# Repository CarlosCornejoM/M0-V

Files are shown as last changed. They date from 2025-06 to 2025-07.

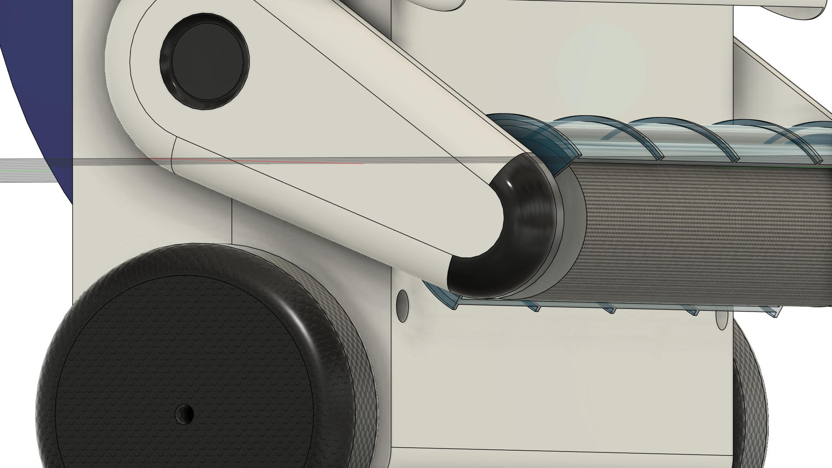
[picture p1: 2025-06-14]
Design/C.png

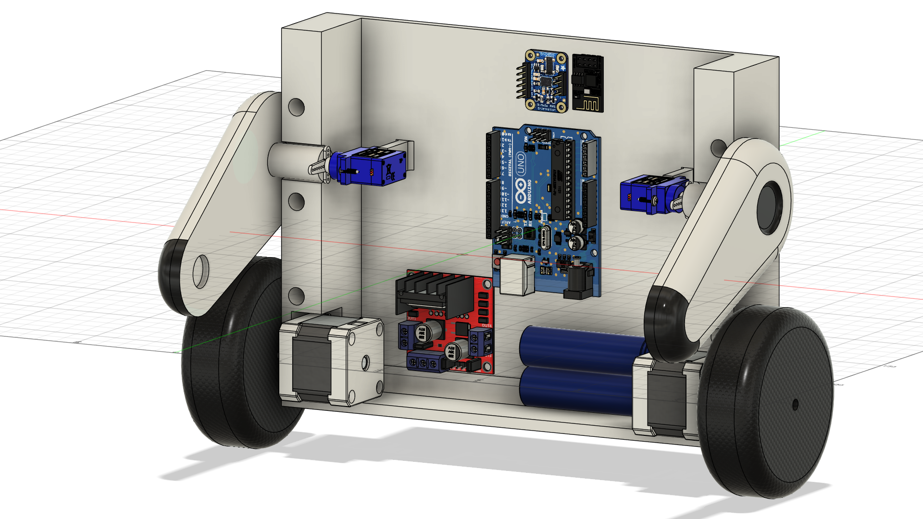
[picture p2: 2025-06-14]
Design/B.png

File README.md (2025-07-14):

# Robot tipo WALL·E con ESP8266 y Arduino

Este repositorio contiene el código fuente y documentación de un robot inspirado en WALL·E (modelo M0-V) que emplea un Arduino (Uno/Nano) para control y un ESP8266 como interfaz web para monitoreo y control remoto en tiempo real.

## Descripción general

### Arduino Uno/Nano:
- Inicializa y calibra el sensor MPU6050 con filtros digitales y pasa-bajos de 20Hz
- Controla dos motores paso a paso NEMA17 (200 pasos/rev) con drivers DRV8825
- Mueve dos servomotores SG90 (0-180°) con control suavizado
- Ejecuta un control PID para equilibrar el sistema pendular invertido con anti-windup
- Gestiona motor DC con control PWM y H-bridge
- Envía telemetría periódica por puerto serie (115200 bps)

### ESP8266:
- Se conecta a la red WiFi (configurable en ESP8266.ino)
- Sirve una interfaz web desde index_html.h
- Establece un WebSocket en el puerto 81 para comunicación bidireccional
- Emite un JSON con el estado completo cada 20 ms
- Recibe comandos desde la página web para control remoto

### Interfaz web:
- Panel de valores de sensor (pitch, roll, yaw, aceleración, temperatura)
- Consola serial con logs en tiempo real
- Gráficos de latencia WebSocket, RPM de steppers y parámetros PID
- Controles para ajustar servos, RPM, PID y reproducir audio
- Monitoreo de estado de LEDs (ESP, Arduino, DC)
- Soporte para gamepad/joystick

## Especificaciones técnicas

### Hardware requerido:
- Arduino Uno + ESP8266
- MPU6050 (giroscopio/acelerómetro)
- 2x Motor NEMA17 con drivers DRV8825
- 2x Servomotor SG90
- Motor DC con H-bridge
- Componentes electrónicos varios

### Características del sistema:
- Comunicación serie: 115200 bps
- Velocidad I2C: 100kHz (estabilidad mejorada)
- Filtro digital MPU6050: 20Hz pasa-bajos
- Control PID: 20ms de período
- Telemetría MPU: 20ms de período
- WebSocket: 20ms de actualización
- MAX_RPM configurable: 30 RPM por defecto

## Flujo de funcionamiento

### 1. Inicialización:
- Arduino arranca módulos: parámetros, steppers, motores DC, MPU, comunicación serie, PID
- ESP8266 arranca en modo station, se conecta al SSID configurado y lanza el servidor HTTP y WebSocket

### 2. Telemetría:
Arduino envía mensajes serial con prefijos:
- `[ANGLES,pitch,roll,yaw,temp]` - Ángulos y temperatura
- `[RPM1,val]`, `[RPM2,val]` - RPM de steppers
- `[PID,error,output,integral]` - Estados del PID
- ESP8266 parsea y actualiza su estado interno
- Cada 20 ms envía por WebSocket un JSON con todos los campos

### 3. Interfaz web:
- Conexión WebSocket en `ws://<IP>:81/`
- Actualización en tiempo real de valores y gráficos
- Envío de comandos JSON:
  - `{"cmd":"setServos","a1":...,"a2":...}` - Control de servos
  - `{"cmd":"setMRPM","rpm":...}` - RPM máximo de steppers
  - `{"cmd":"setPID","sp":...,"kp":...,"ki":...,"kd":...}` - Parámetros PID
  - `{"cmd":"playMelody"}`, `{"cmd":"playAudio"}` - Reproducción audio
  - `{"cmd":"startSiren"}`, `{"cmd":"stopSiren"}` - Control sirena
  - `{"cmd":"espOn"}/{"cmd":"espOff"}` - LEDs ESP
  - `{"cmd":"unoOn"}/{"cmd":"unoOff"}` - LEDs Arduino
  - `{"cmd":"dcOn"}/{"cmd":"dcOff"}` - Motor DC
  - `{"cmd":"JOY_L","x":...,"y":...}` - Control diferencial steppers
  - `{"cmd":"gamepad",...}` - Control por gamepad

### 4. Control por gamepad:
- La página captura un joystick Gamepad API
- Stick izquierdo: comando JOY_L (control diferencial steppers)
- Stick derecho: ajuste automático de servos
- Gatillos: nivel DC
- Botones mapeados a acciones definidas por el usuario

## Configuración de pines

### Arduino:
- **MPU6050**: I2C (SDA/SCL)
- **Steppers**: DIR1=2, STEP1=3, DIR2=4, STEP2=5, EN1=A0, EN2=A1
- **H-bridge**: ENA=14, ENB=7, IN1=8, IN2=12, IN3=10, IN4=13
- **Servos**: SERVO1=6, SERVO2=9
- **Motor DC**: PWM=11
- **Ultrasonido**: TRIG=A3, ECHO=6
- **LED**: LED_BUILTIN

### ESP8266:
- **Comunicación serie**: RX/TX con Arduino
- **LED**: D4 (GPIO2)
- **WiFi**: Antena integrada

## Algoritmos implementados

### Control PID:
- Período: 20ms
- Anti-windup: Integral limitada a ±1000
- Filtro derivativo: Pasa-bajos con coeficiente 0.7
- Salida limitada a MAX_RPM

### Control de steppers:
- Suavizado exponencial: Factor 0.15
- Aceleración: 2x velocidad máxima
- Frecuencia de ejecución: 500Hz máximo
- Habilitación automática por velocidad

### Filtrado MPU6050:
- Filtro digital interno: 20Hz
- Filtro pasa-bajos software: Coeficiente 0.8
- Verificación de conexión continua
- Manejo de errores robusto

## Configuración

### 1. En ESP8266.ino, ajusta:
```cpp
const char* ssid     = "MOV";
const char* password = "12345678";
```

### 2. Verifica los pines en Param.ino y ESP8266.ino

### 3. Flashea primero el firmware de Arduino, luego el del ESP8266

### 4. Abre el navegador en la IP mostrada por el ESP en el monitor serie

## Optimizaciones implementadas

### Rendimiento:
- Filtros de software para reducir ruido
- Suavizado exponencial en steppers
- Telemetría adaptativa (solo envía si hay cambios significativos)
- Frecuencias de ejecución optimizadas

### Estabilidad:
- Velocidad I2C reducida (100kHz)
- Filtros anti-jitter en steppers
- Verificación de conexión MPU6050
- Manejo de errores en comunicación serie

### Eficiencia:
- Reducción de spam en telemetría
- Buffers optimizados
- Timers independientes para cada módulo
- Control de flujo en WebSocket

## Roadmap

- Optimización de filtros del MPU6050 y suavizado de steppers
- Mejoras en logging y manejo de errores en la web
- Implementación de PCB personalizada
- Soporte para múltiples sensores
- Integración con ROS (Robot Operating System)
- Modo autónomo con navegación

## Troubleshooting

### Problemas comunes:
- **MPU6050 se corrompe**: Verificar conexiones I2C y alimentación estable
- **Steppers con jitter**: Ajustar SMOOTH_FACTOR y verificar drivers
- **WebSocket desconecta**: Verificar potencia de señal WiFi
- **PID inestable**: Ajustar parámetros Kp, Ki, Kd gradualmente

### Logs de debug:
- Monitor serie Arduino: Estados de sensores y actuadores
- Consola web: Comunicación WebSocket y errores JavaScript
- Debug ESP8266: Información de conexión WiFi y memoria

¡Gracias por tu interés! Cualquier issue o PR es bienvenido.

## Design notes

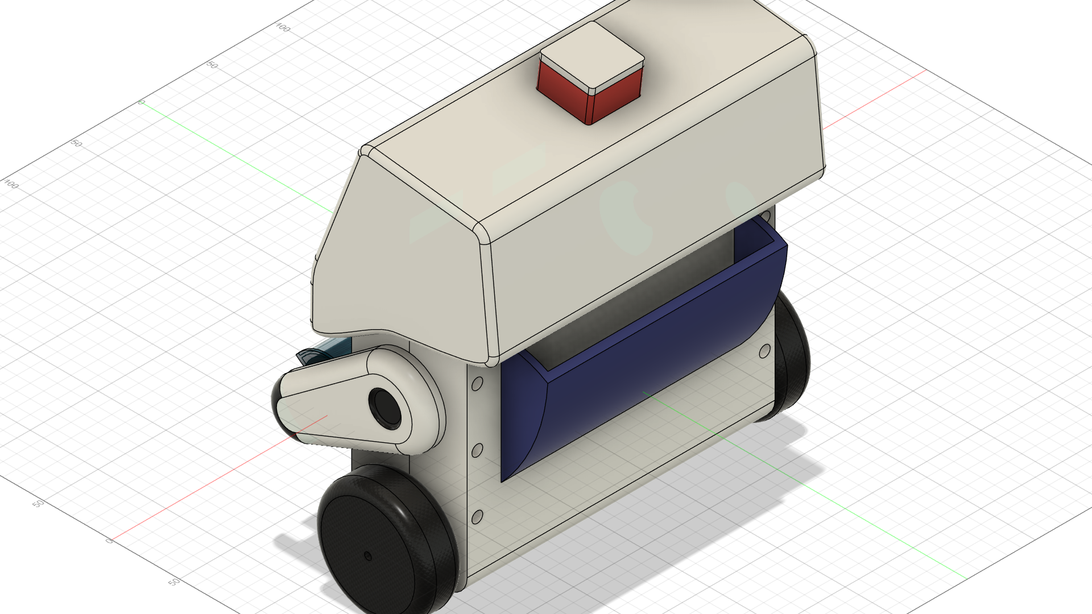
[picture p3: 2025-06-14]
Design/E.png

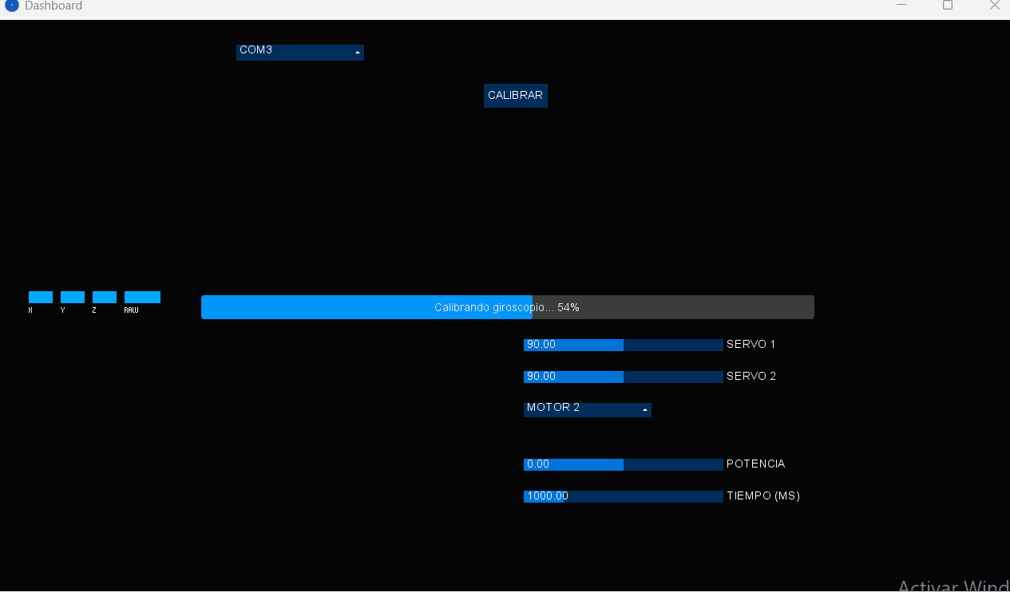
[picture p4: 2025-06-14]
Design/Animation3.gif

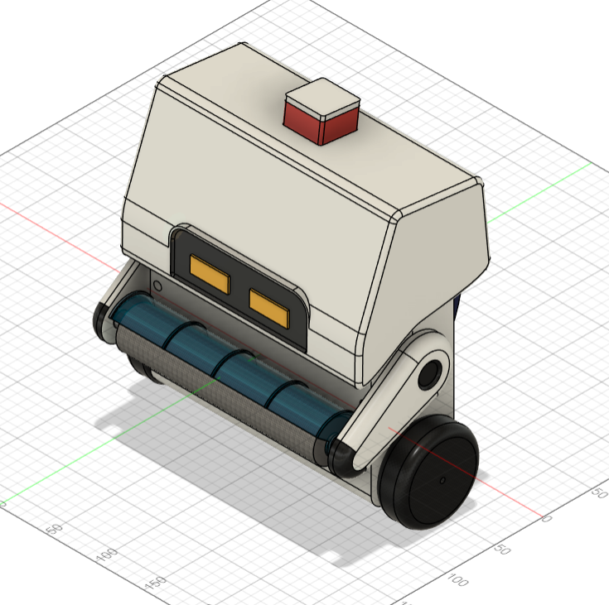
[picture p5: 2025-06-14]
Design/A.png

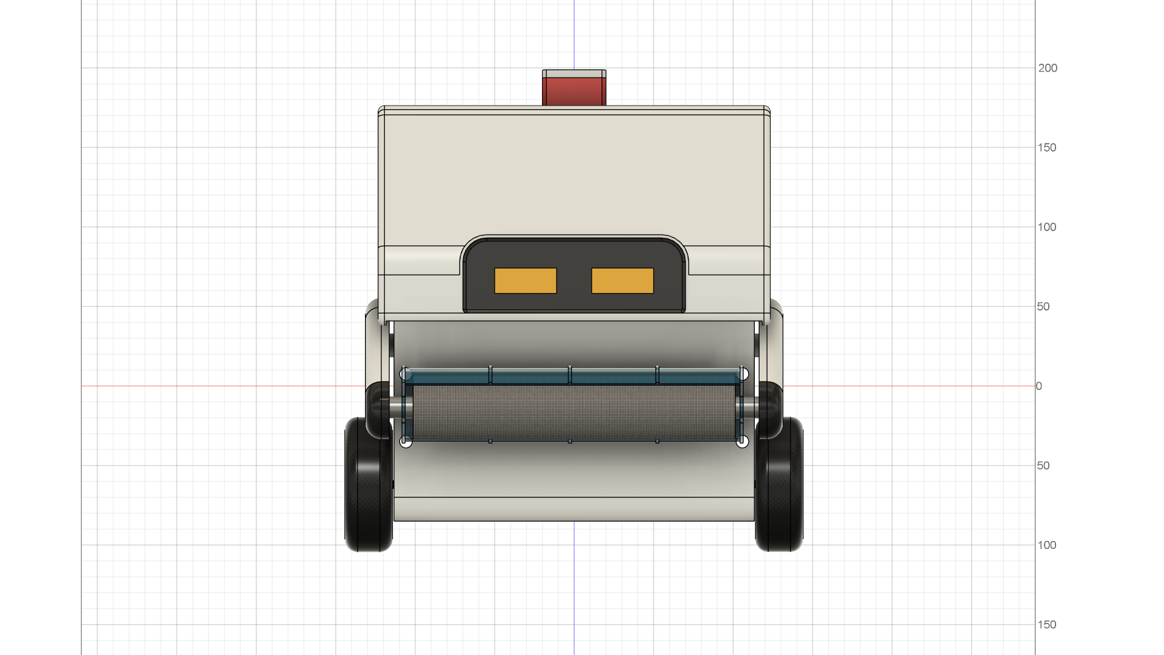
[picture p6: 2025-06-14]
Design/D.png

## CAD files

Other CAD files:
Design/experimento.f3z

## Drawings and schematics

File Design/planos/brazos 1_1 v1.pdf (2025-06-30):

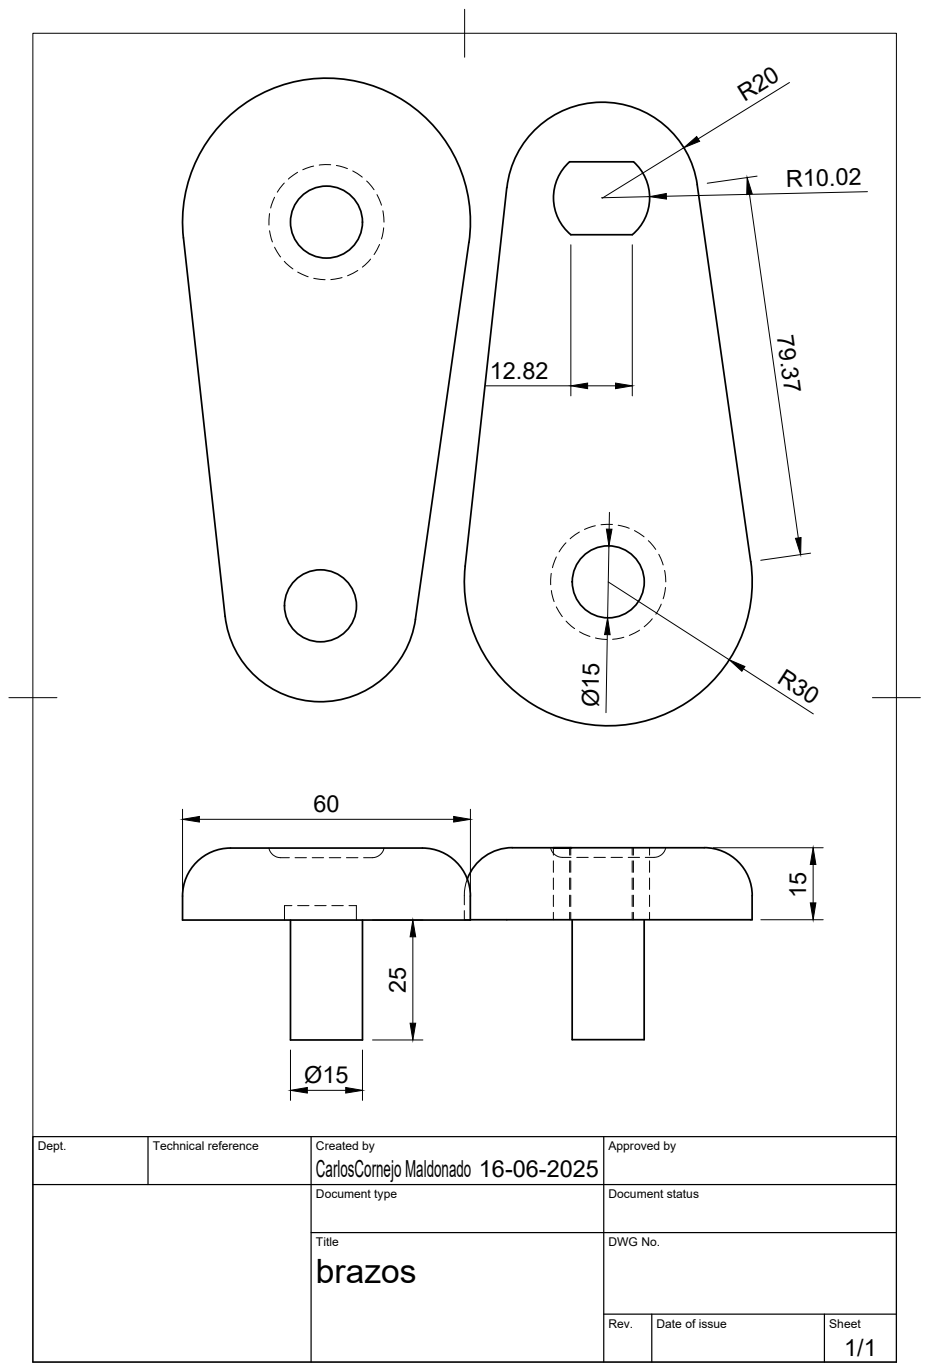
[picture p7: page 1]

Dept. | Technical reference | Created by CarlosCornejo Maldonado 16-06-2025 | Approved by

Document type | Document status

Title brazos | DWG No.

Rev. | Date of issue | Sheet 1/1

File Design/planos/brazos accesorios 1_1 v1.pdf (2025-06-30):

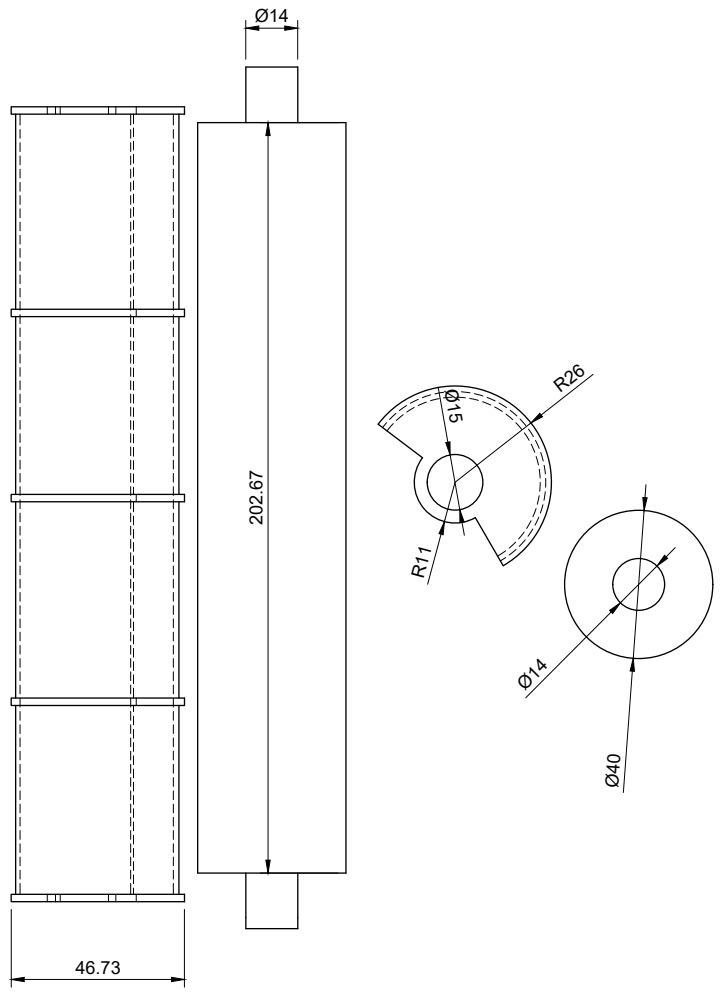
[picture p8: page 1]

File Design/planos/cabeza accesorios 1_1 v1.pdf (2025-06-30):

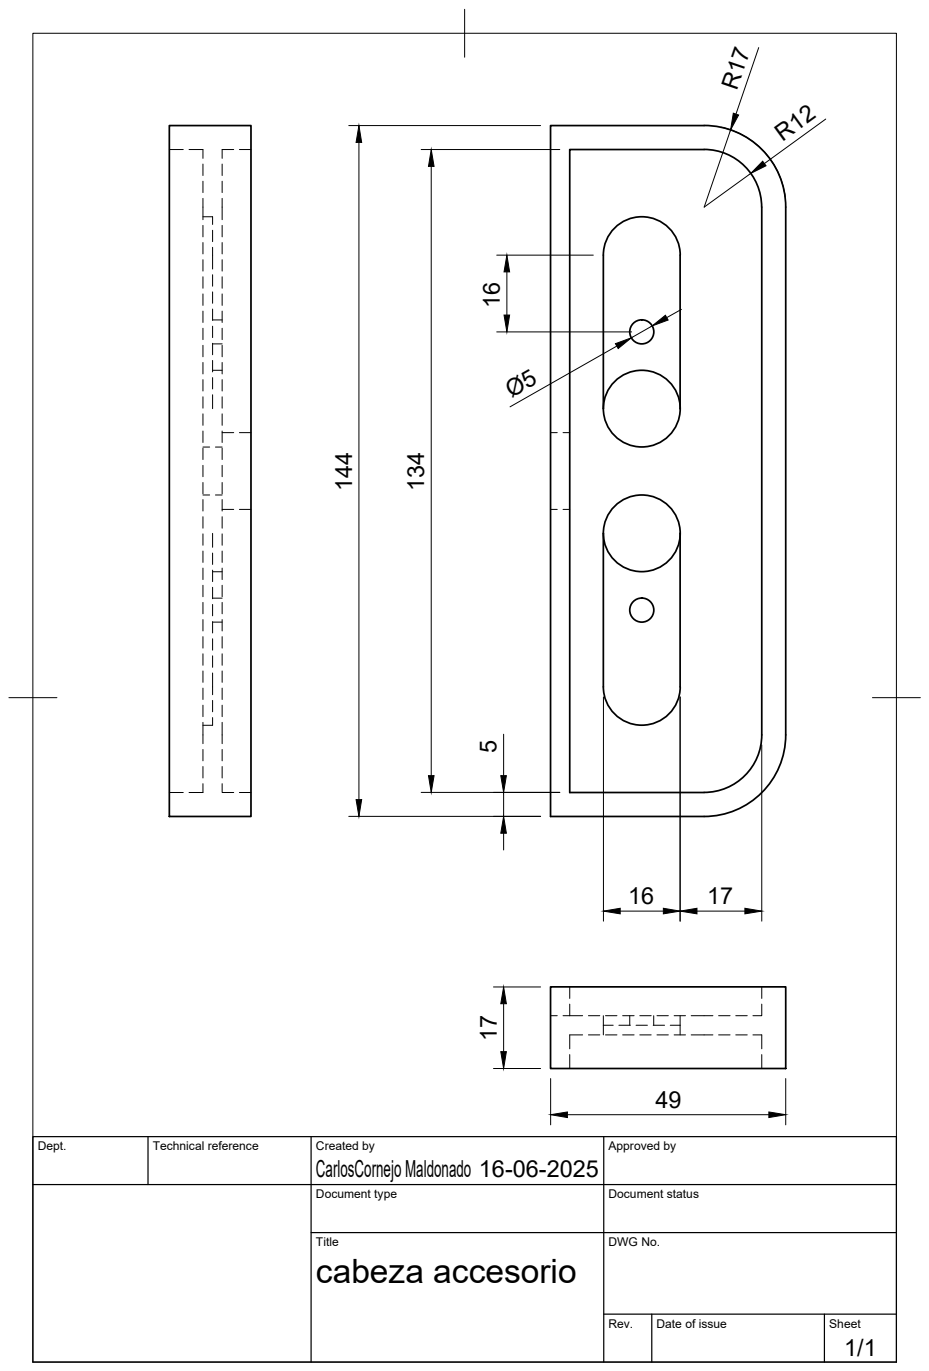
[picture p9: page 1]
CarlosCornejo Maldonado 144

Dept. | Technical reference | Created by 16-06-2025 | Approved by

Document type | Document status

Title cabeza accesorio | DWG No.

Rev. | Date of issue | Sheet 1/1

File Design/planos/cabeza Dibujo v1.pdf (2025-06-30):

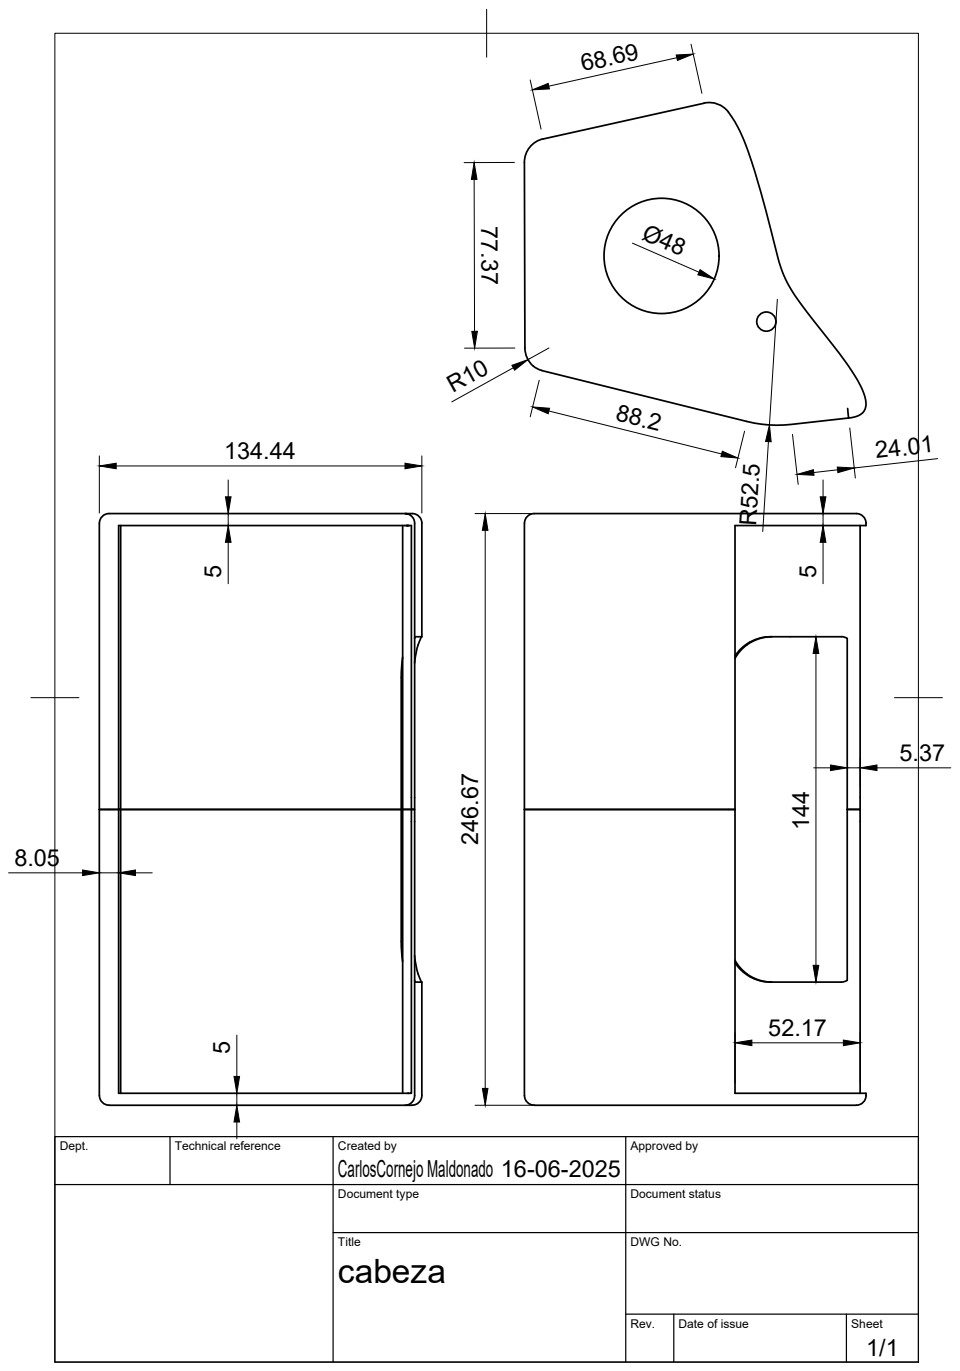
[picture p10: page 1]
CarlosCornejo Maldonado77.37

Dept. | Technical reference | Created by 16-06-2025 | Approved by

Document type | Document status

Title cabeza | DWG No.

Rev. | Date of issue | Sheet 1/1

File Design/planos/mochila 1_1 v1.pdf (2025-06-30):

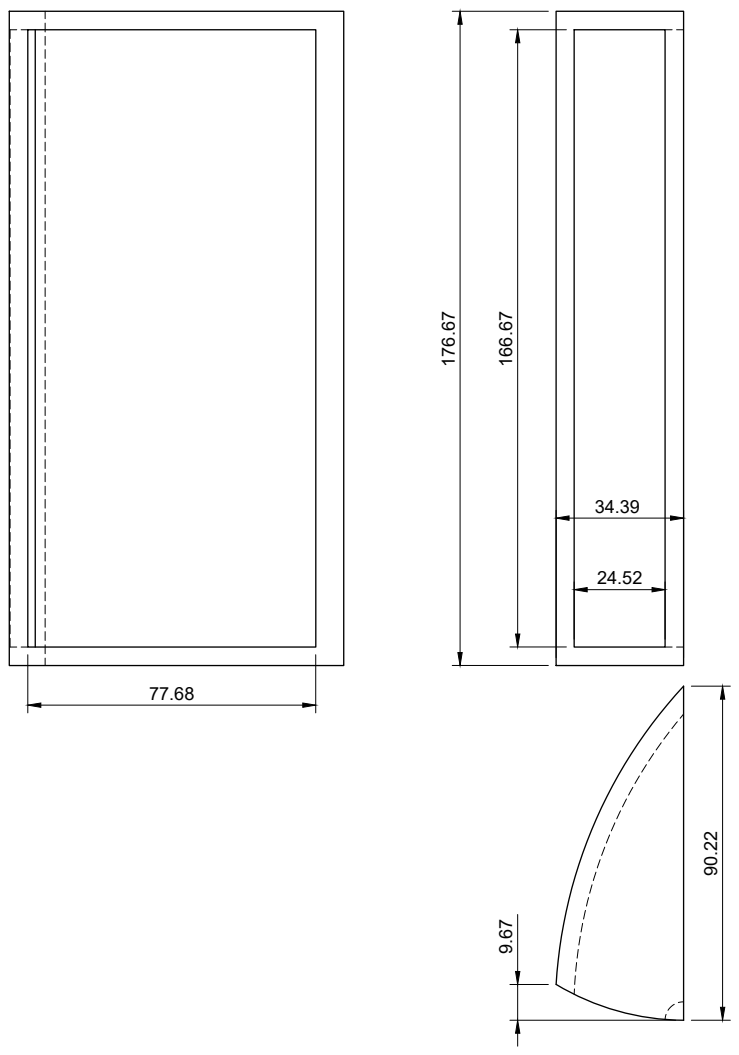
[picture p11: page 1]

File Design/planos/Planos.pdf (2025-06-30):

Dept.; Technical reference; Created by; Approved by; Document type; Document status; Title; DWG No.; Rev.; Date of issue; Sheet; brazos; CarlosCornejo Maldonado

202.67

Ø14

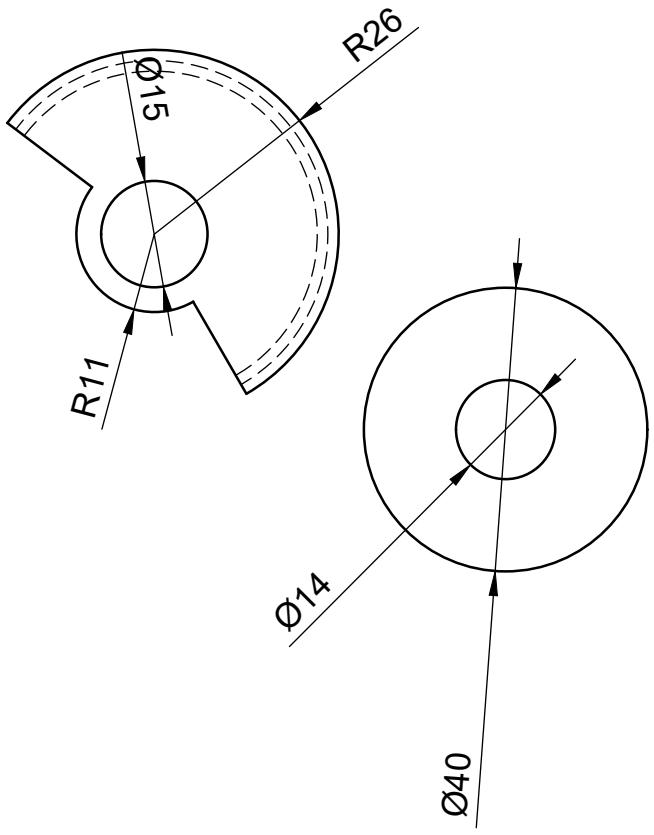
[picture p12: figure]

46.73 | Ø⁴⁰

17 ¹⁶

Dept.; Technical reference; Created by; Approved by; Document type; Document status; Title; DWG No.; cabeza accesorio

CarlosCornejo Maldonado ¹⁴⁴

# CarlosCornejo Maldonado⁷⁷.37 Ø48 246.67

Dept.; Technical reference; Created by; Approved by; Document type; Document status; Title; DWG No.; cabeza

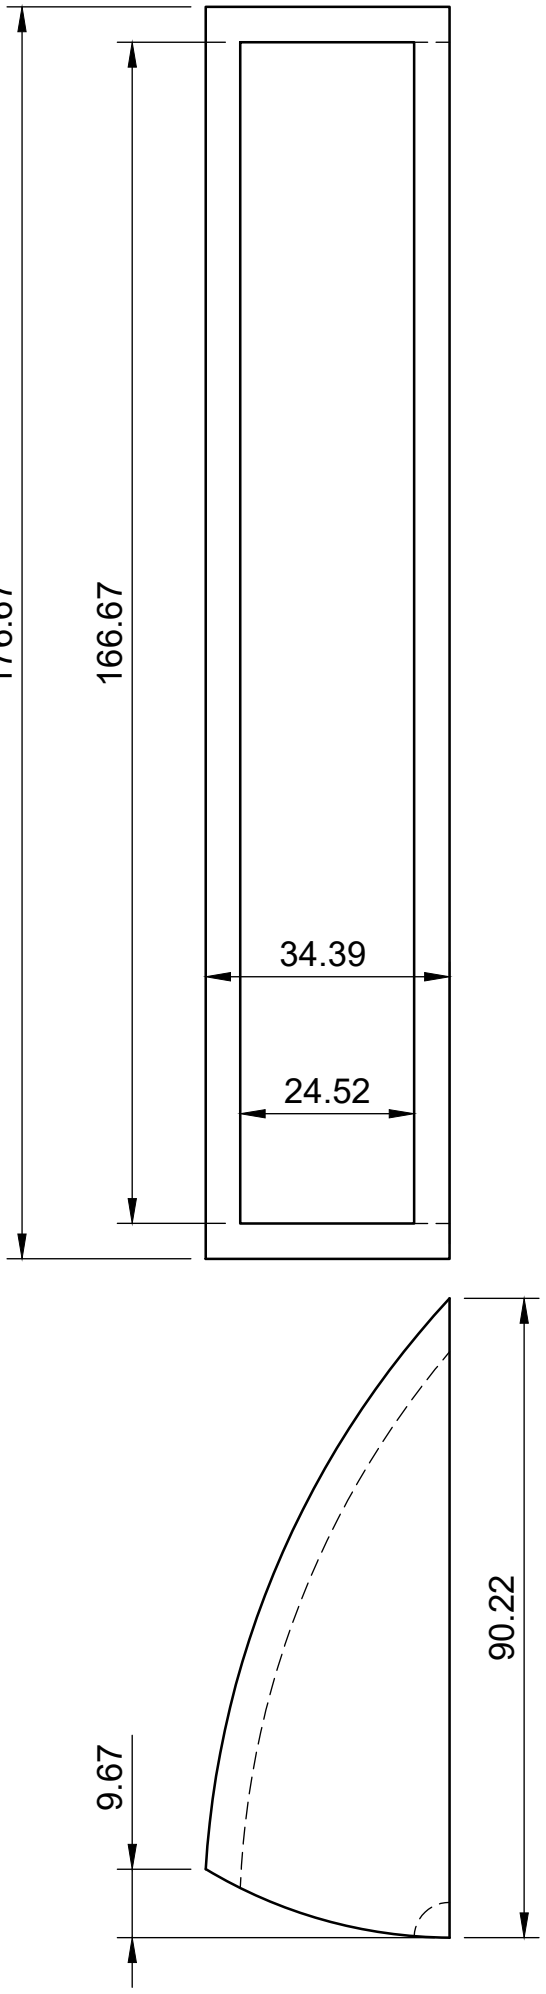
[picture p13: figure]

176.67

77.68 | 9.67

69.1

69.8

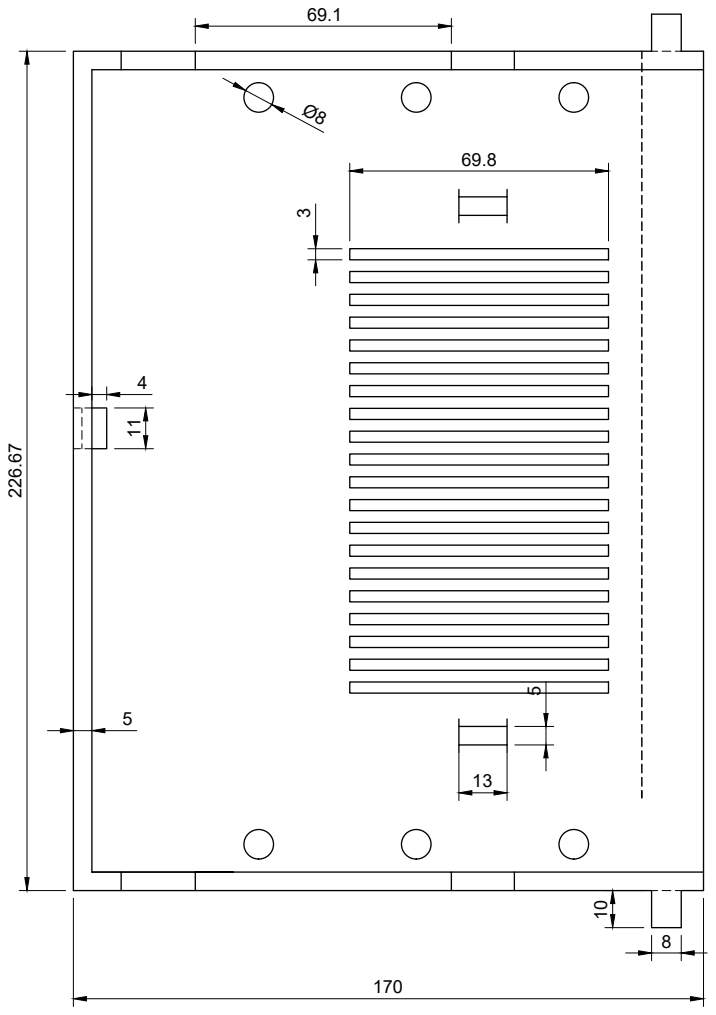
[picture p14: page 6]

42.5

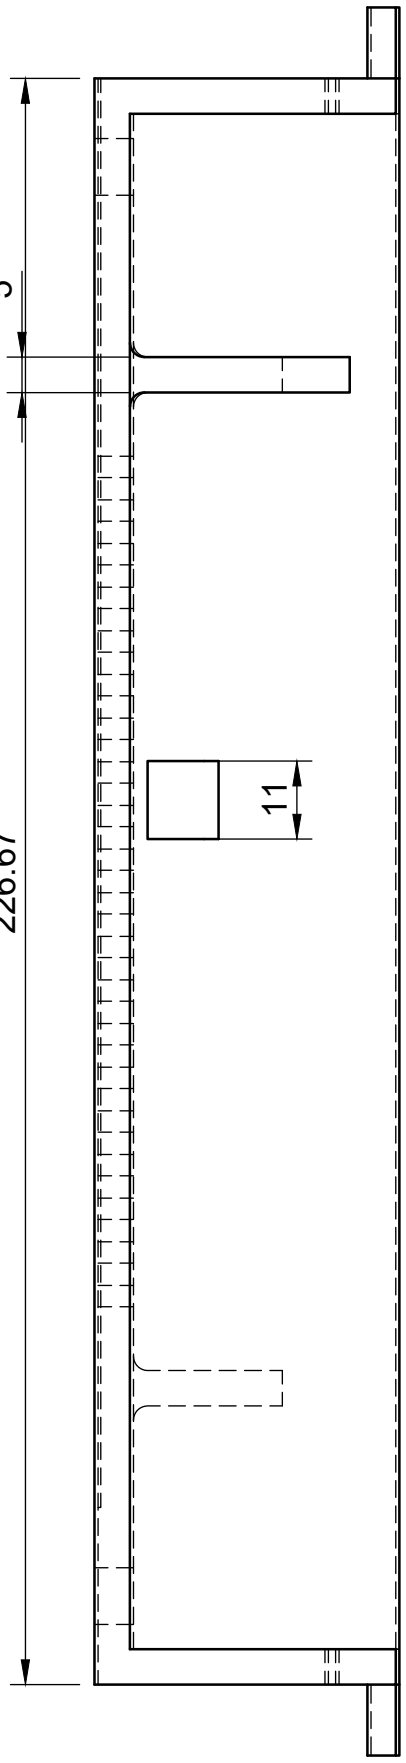
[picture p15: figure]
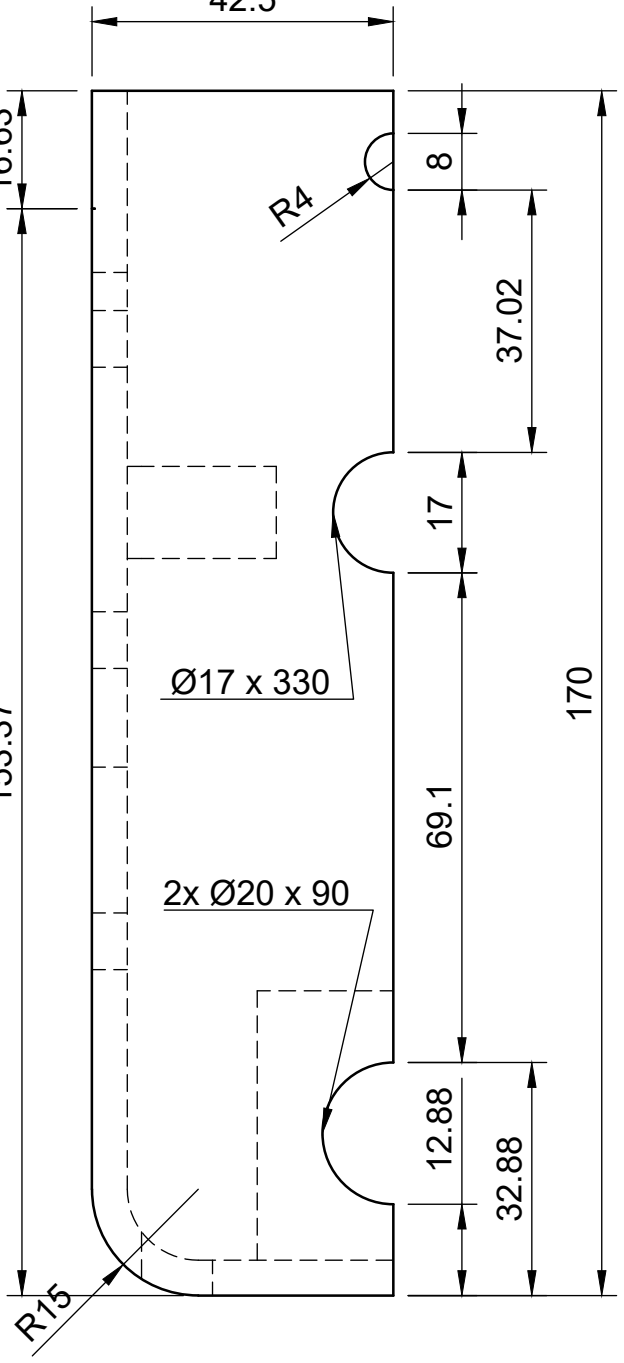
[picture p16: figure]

2x Ø20 x 90 R4 R¹⁵ | 69.1 | 37.02 12.88 816.63 153.37 | 32.88 17 | 226.67 | 11 5

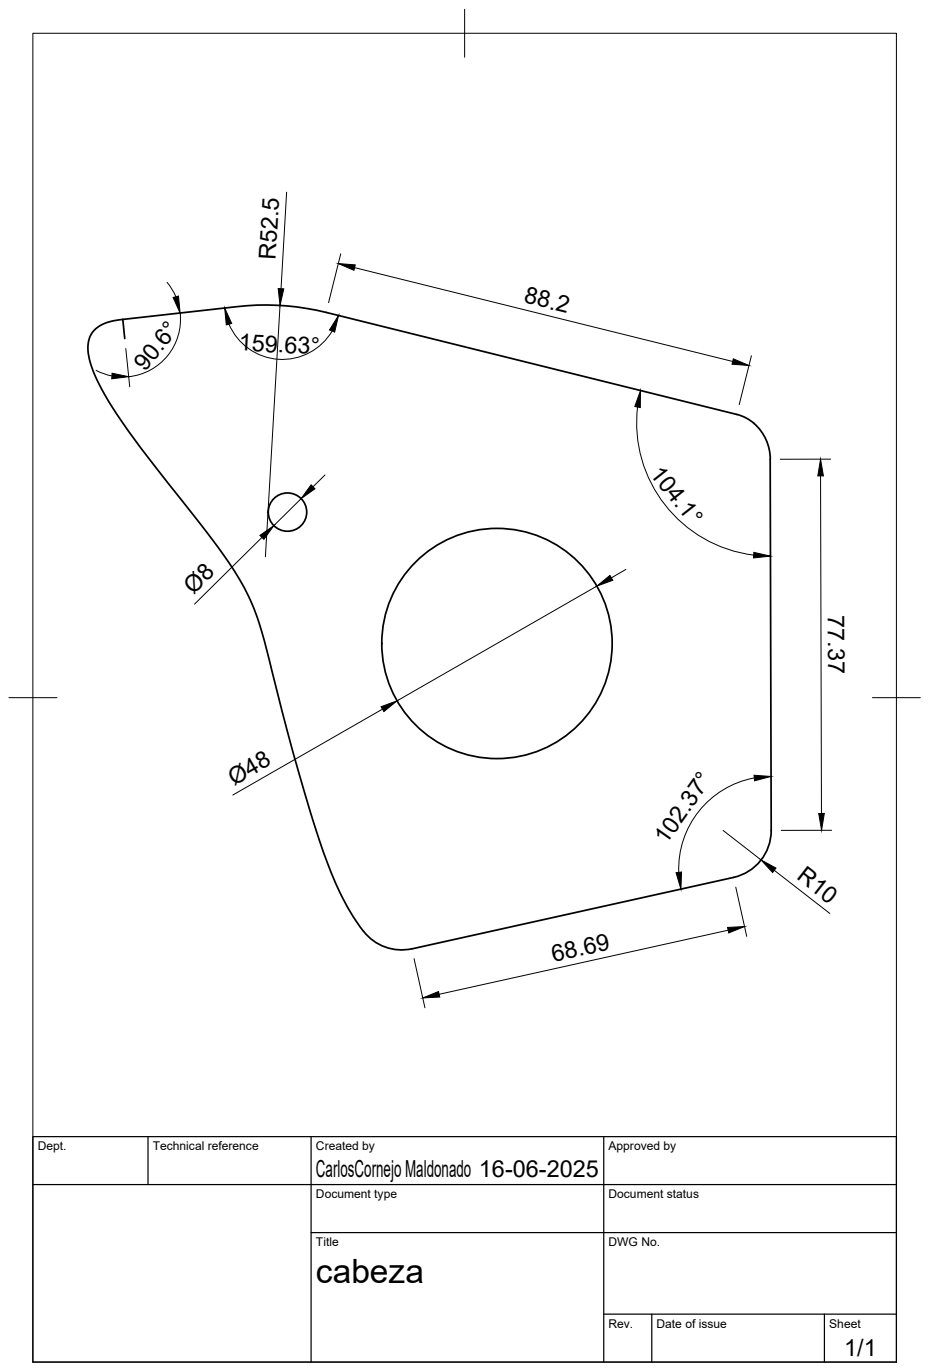
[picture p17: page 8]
Dept.; Technical reference; Created by; Approved by; Document type; Document status; Title; DWG No.; cabeza; CarlosCornejo Maldonado

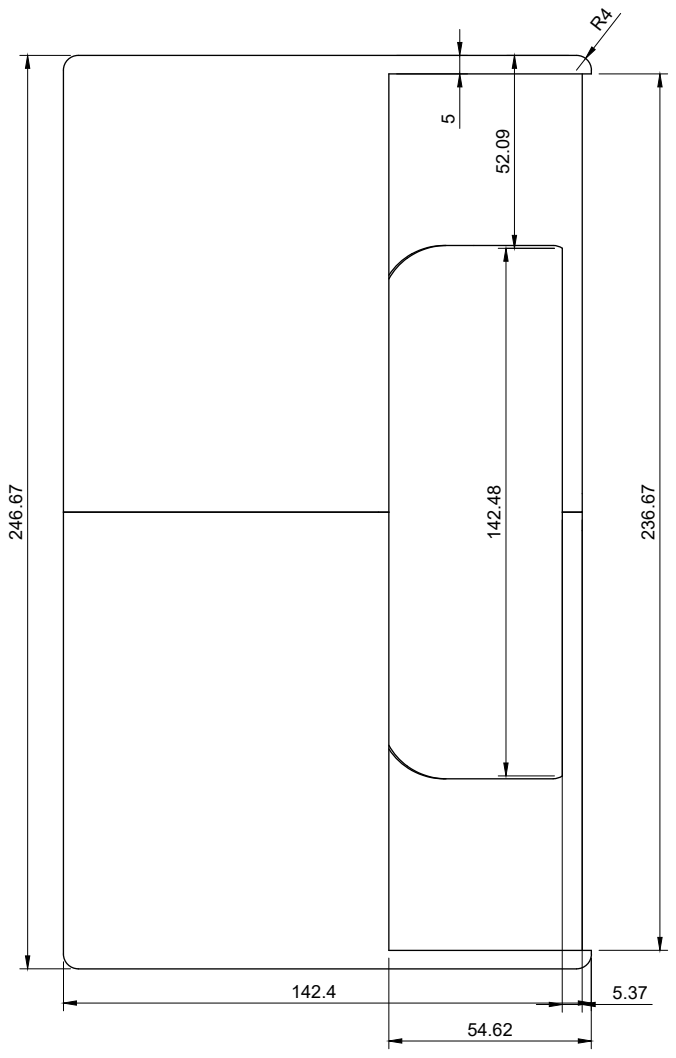
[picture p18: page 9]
54.62¹⁴².48




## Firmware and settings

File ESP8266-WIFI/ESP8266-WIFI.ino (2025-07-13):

#include <ESP8266WiFi.h>
#include <ESP8266WebServer.h>
#include <ESP8266mDNS.h>
#include <WebSocketsServer.h>
#include <ArduinoJson.h>
#include "index_html.h"
#include <Arduino.h>
#include "AudioFileSourcePROGMEM.h"
#include "AudioGeneratorWAV.h"
#include "AudioOutputI2SNoDAC.h"
#include "audio.h"

// ======= CONFIG =======
const char* ssid     = "Mov";
const char* password = "12345678";

const int audioPin   = 3;
const int ledESP     = 14;
const int ojoIzqPin  = 4;    // ojo izquierdo
const int ojoDerPin  = 16;   // ojo derecho
const int cabezaPin  = 12;   // sirena

// ======= PWM =======
const int PWM_MAX = 1023;
const int PWM_MIN = 0;

// ======= OPTIMIZED CONSTANTS =======
const size_t MAX_SERIAL_BUF   = 128;
const float  JOY_L_THRESHOLD  = 0.05f;
const uint32_t DC_SEND_INTERVAL  = 50;
const uint32_t BROADCAST_INTERVAL = 20;
const uint8_t  DC_THRESHOLD      = 5;
const uint32_t SERIAL_TIMEOUT    = 1000;


// ======= SIRENA STATE =======
struct SirenState {
  bool     active     = false;
  uint32_t startTime  = 0;
  uint16_t freqLo     = 800;
  uint16_t freqHi     = 2000;
  uint32_t period     = 2000; // ms para barrido completo
} siren;

// ======= BLINK PATTERNS OJOS =======
const uint8_t  N_PATTERNS    = 4;
const uint8_t  MAX_BLINK_LEN = 8;
const uint32_t blinkPatterns[N_PATTERNS][MAX_BLINK_LEN] = {
  {  80,200,   0,0,0,0,0,0 },  // rápido
  { 150, 50,150,200, 0,0,0,0 }, // doble
  { 200,500,   0,0,0,0,0,0 },   // lento
  {  80, 80,120,120, 90,300,0,0 } // mixto
};
uint8_t  curPatternIdx = 0;
uint8_t  curBlinkStep  = 0;
uint32_t nextBlinkTime = 0;
bool     blinkOn       = false;

// ======= NON-BLOCKING PAUSE =======
uint32_t pauseEnd = 0;
void delayFreePause(uint32_t ms) { pauseEnd = millis() + ms; }
bool inPause() { return millis() < pauseEnd; }

// ======= FLAG PARA MANTENER OJOS ENCENDIDOS =======
bool holdEyesOn = false;
bool blinkPatternFinished = false;

// ======= SIRENA PWM PARA CABEZA =======
struct HeadFadeState {
  int     currentValue;
  bool    increasing;
  uint32_t lastUpdate;
  bool    inPause;
  uint32_t pauseEnd;
} headFade;

// Cada ciclo completo (subida + bajada) tarda 2000 ms
const uint32_t HEAD_PERIOD    = 2000;
const uint32_t HEAD_STEP_MS   = 20;
const int      HEAD_STEP      = PWM_MAX / (HEAD_PERIOD / (2 * HEAD_STEP_MS));

void handleHeadSirenBlink() {
  uint32_t now = millis();
  if (now - headFade.lastUpdate < HEAD_STEP_MS) return;
  headFade.lastUpdate = now;
  if (headFade.increasing) {
    headFade.currentValue = min(headFade.currentValue + HEAD_STEP, PWM_MAX);
    if (headFade.currentValue >= PWM_MAX) headFade.increasing = false;
  } else {
    headFade.currentValue = max(headFade.currentValue - HEAD_STEP, PWM_MIN);
    if (headFade.currentValue <= PWM_MIN) headFade.increasing = true;
  }
  analogWrite(cabezaPin, headFade.currentValue);
}

// ======= PWM FADE STATE (para breathing cuando no blink en ojos) =======
struct PWMFadeState {
  int currentValue = PWM_MIN;
  int targetValue  = PWM_MIN;
  uint32_t lastUpdate = 0;
  bool isActive    = false;
} pwmState;

void setPWMTarget(int target) {
  pwmState.targetValue = constrain(target, PWM_MIN, PWM_MAX);
  pwmState.isActive    = true;
  pwmState.lastUpdate  = millis();
}

void handlePWMFade() {
  if (!pwmState.isActive) return;
  uint32_t now = millis();
  if (now - pwmState.lastUpdate < 20) return;
  if (pwmState.currentValue != pwmState.targetValue) {
    if (pwmState.currentValue < pwmState.targetValue) {
      pwmState.currentValue = min(pwmState.currentValue + 20, pwmState.targetValue);
    } else {
      pwmState.currentValue = max(pwmState.currentValue - 20, pwmState.targetValue);
    }
    analogWrite(ojoIzqPin, pwmState.currentValue);
    analogWrite(ojoDerPin, pwmState.currentValue);
    pwmState.lastUpdate = now;
  } else {
    pwmState.isActive = false;
  }
}
// ======= STATE STRUCT (ACTUALIZADA) =======
struct __attribute__((packed)) State {
  uint8_t flags;       // bit0: espOn, bit1: unoOn, bit2: dcOn, bit3: playingMelody, bit4: playingAudio
  uint8_t servo1, servo2;
  int16_t motorVel;
  uint16_t motorTime;
  uint8_t motorSel;
  uint8_t dcValue;
  int16_t joyLX_i, joyLY_i, joyRX_i, joyRY_i;
  uint8_t trig6_i, trig7_i;
  uint16_t btnState;
  int16_t pitch_i, roll_i, yaw_i;
  int16_t accelX_i, accelY_i, accelZ_i;
  int16_t gyroX_i, gyroY_i, gyroZ_i;  // ¡AGREGADO!
  int16_t temperature_i;
  uint16_t ultrasonic_i;
  int16_t setPoint_i;
  uint16_t kp_i, ki_i, kd_i;
  int16_t pidError_i, pidOutput_i;
  uint16_t pidAngle;
  int16_t currentRPM_i;
} state;

inline bool getEspOn()        { return state.flags & 0x01; }
inline bool getUnoOn()        { return state.flags & 0x02; }
inline bool getDcOn()         { return state.flags & 0x04; }
inline bool isPlayingMelody() { return state.flags & 0x08; }
inline bool isPlayingAudio()  { return state.flags & 0x10; }
inline void setEspOn(bool v)        { state.flags = (state.flags & ~0x01) | (v ? 0x01 : 0); }
inline void setUnoOn(bool v)        { state.flags = (state.flags & ~0x02) | (v ? 0x02 : 0); }
inline void setDcOn(bool v)         { state.flags = (state.flags & ~0x04) | (v ? 0x04 : 0); }
inline void setPlayingMelody(bool v){ state.flags = (state.flags & ~0x08) | (v ? 0x08 : 0); }
inline void setPlayingAudio(bool v) { state.flags = (state.flags & ~0x10) | (v ? 0x10 : 0); }

// ======= GLOBALS =======
String serialBuf;
ESP8266WebServer server(80);
WebSocketsServer webSocket(81);

// ======= SERIAL BUFFER =======
void appendSerialBuf(const String &s) {
  serialBuf += s;
  if (serialBuf.length() > MAX_SERIAL_BUF) {
    serialBuf = serialBuf.substring(serialBuf.length() - MAX_SERIAL_BUF);
  }
}

// ======= JOYSTICK STATE =======
struct JoystickState {
  float lastFX = 0.0f, lastFY = 0.0f;
  uint32_t lastUpdate = 0;
} joyState;

// ======= DC CONTROL STATE =======
struct DCState {
  uint32_t lastSent = 0;
  uint8_t  lastValue = 0;
} dcState;

// ======= AUDIO PLAYBACK =======
AudioGeneratorWAV*      wavPlayer;
AudioFileSourcePROGMEM* wavFile;
AudioOutputI2SNoDAC*    wavOut;

void initAudio() {
  wavOut    = new AudioOutputI2SNoDAC();
  wavPlayer = new AudioGeneratorWAV();
}

void playAudio() {
  if (isPlayingAudio()) return;
  if (wavFile) { delete wavFile; wavFile = nullptr; }
  wavFile = new AudioFileSourcePROGMEM(audio, sizeof(audio));
  wavPlayer->begin(wavFile, wavOut);
  setPlayingAudio(true);
}

void handleAudio() {
  if (!isPlayingAudio()) return;
  if (!wavPlayer->loop()) {
    wavPlayer->stop();
    setPlayingAudio(false);
  }
}

// ======= ROBOT-STYLE MELODY =======
const uint16_t melodyData[] PROGMEM = {
  1000,100, 800,100, 600,100, 400,100,
   400,100, 600,100, 800,100,1000,200
};
const uint8_t melodyLen = 8;
struct MelodyState {
  uint8_t  noteIndex   = 0;
  uint32_t noteEndTime = 0;
} melodyState;

void playMelodyAsync() {
  setPlayingMelody(true);
  melodyState.noteIndex   = 0;
  melodyState.noteEndTime = millis();
}

void handleMelody() {
  if (!isPlayingMelody()) return;
  uint32_t now = millis();
  if (now < melodyState.noteEndTime) return;
  if (melodyState.noteIndex >= melodyLen) {
    noTone(audioPin);
    setPlayingMelody(false);
    return;
  }
  uint16_t freq = pgm_read_word(&melodyData[melodyState.noteIndex*2]);
  uint16_t dur  = pgm_read_word(&melodyData[melodyState.noteIndex*2+1]);
  tone(audioPin, freq, dur);
  melodyState.noteEndTime = now + dur + 50;
  melodyState.noteIndex++;
}

// ======= DC UPDATE =======
void updateDCFromTrigger() {
  uint32_t now = millis();
  if (now - dcState.lastSent < DC_SEND_INTERVAL) return;
  uint8_t dcVal = state.trig7_i;
  if (abs(dcVal - dcState.lastValue) > DC_THRESHOLD) {
    char buf[16];
    float df = dcVal/255.0f;
    snprintf_P(buf, sizeof(buf), PSTR("[DC,%.2f]"), df);
    Serial.println(buf);
    //Serial1.println(buf);
    appendSerialBuf(buf);
    setDcOn(dcVal > 0);
    state.dcValue    = dcVal;
    dcState.lastValue = dcVal;
    dcState.lastSent  = now;
  }
}

// ======= OPTIMIZED SERIAL INPUT =======
void handleSerial() {
  static String lineBuf;
  static uint32_t lastActivity = 0;
  uint32_t now = millis();
  
  while (Serial.available()) {
    char c = Serial.read();
    lastActivity = now;
    
    if (c == '\n' || c == '\r') {
      if (lineBuf.length() > 0) {
        processSerialLine(lineBuf+ "\n");
        lineBuf = "";
      }
    } else {
      lineBuf += c;
      // Prevent buffer overflow
      if (lineBuf.length() > 64) {
        lineBuf = "";
      }
    }
  }
  
  // Clear incomplete lines after timeout
  if (lineBuf.length() > 0 && (now - lastActivity > SERIAL_TIMEOUT)) {
    lineBuf = "";
  }
}
// Llama a processSerialLine(line) cada vez que recibas una línea completa de Serial
void processSerialLine(const String& line) {
  if (line.length() < 3) return;
  char type = line.charAt(1);
  const char* data = line.c_str();

  // Siempre guarda la línea cruda para mostrarla en la web
  appendSerialBuf(line);

  switch (type) {
    case 'A':  // ANGLES o ACCEL
      if (line.startsWith("[ANGLES,")) {
        float p, r, y;
        if (sscanf(data + 8, "%f,%f,%f", &p, &r, &y) == 3) {
          state.pitch_i = (int16_t)round(p * 100);
          state.roll_i  = (int16_t)round(r * 100);
          state.yaw_i   = (int16_t)round(y * 100);
        }
      }
      else if (line.startsWith("[ACCEL,")) {
        float ax, ay, az;
        if (sscanf(data + 7, "%f,%f,%f", &ax, &ay, &az) == 3) {
          state.accelX_i = (int16_t)round(ax * 1000);
          state.accelY_i = (int16_t)round(ay * 1000);
          state.accelZ_i = (int16_t)round(az * 1000);
        }
      }
      break;

    case 'G':  // GYRO
      if (line.startsWith("[GYRO,")) {
        float gx, gy, gz;
        if (sscanf(data + 6, "%f,%f,%f", &gx, &gy, &gz) == 3) {
          state.gyroX_i = (int16_t)round(gx * 100);
          state.gyroY_i = (int16_t)round(gy * 100);
          state.gyroZ_i = (int16_t)round(gz * 100);
        }
      }
      break;

    case 'T':  // TEMP
      if (line.startsWith("[TEMP,")) {
        float T;
        if (sscanf(data + 6, "%f", &T) == 1) {
          state.temperature_i = (int16_t)round(T * 100);
        }
      }
      break;

    case 'U':  // ULTRASONIC
      if (line.startsWith("[US,")) {
        float d;
        if (sscanf(data + 4, "%f", &d) == 1) {
          state.ultrasonic_i = (uint16_t)round(d * 100);
        }
      }
      break;

    case 'P':  // PID feedback
      if (line.startsWith("[PID,")) {
        float e, o; int a;
        if (sscanf(data + 5, "%f,%f,%d", &e, &o, &a) == 3) {
          state.pidError_i  = (int16_t)round(e * 100);
          state.pidOutput_i = (int16_t)round(o * 100);
          state.pidAngle    = (uint16_t)a;
        }
      }
      break;

    case 'R':  // RPM
      if (line.startsWith("[RPM,")) {
        float rpm;
        if (sscanf(data + 5, "%f", &rpm) == 1) {
          state.currentRPM_i = (int16_t)round(rpm * 10.0f);
        }
      }
      break;

    default:
      // Otros tipos de mensajes: los mostramos crudos pero no parseamos
      break;
  }
}




// ======= BROADCAST STATE (ACTUALIZADO) =======
void broadcastState() {
  handleSerial();
  DynamicJsonDocument doc(512);  // Aumentado el tamaño para datos adicionales
  
  doc["espOn"]      = getEspOn();
  doc["unoOn"]      = getUnoOn();
  doc["dcOn"]       = getDcOn();
  doc["servo1"]     = state.servo1;
  doc["servo2"]     = state.servo2;
  doc["motorVel"]   = state.motorVel;
  doc["motorTime"]  = state.motorTime;
  doc["motorSel"]   = state.motorSel;
  doc["dcValue"]    = state.dcValue;
  
  // Joystick
  doc["joyLX"]      = state.joyLX_i*(1.0f/32767.0f);
  doc["joyLY"]      = state.joyLY_i*(1.0f/32767.0f);
  doc["joyRX"]      = state.joyRX_i*(1.0f/32767.0f);
  doc["joyRY"]      = state.joyRY_i*(1.0f/32767.0f);
  doc["trig6"]      = state.trig6_i*(1.0f/255.0f);
  doc["trig7"]      = state.trig7_i*(1.0f/255.0f);
  
  // Sensores
  doc["ultrasonic"] = state.ultrasonic_i*0.01f;
  doc["temperature"]= state.temperature_i*0.01f;
  
  // IMU - Ángulos
  doc["pitch"]      = state.pitch_i*0.01f;
  doc["roll"]       = state.roll_i*0.01f;
  doc["yaw"]        = state.yaw_i*0.01f;
  
  // IMU - Acelerómetro
  doc["accelX"]     = state.accelX_i*0.001f;
  doc["accelY"]     = state.accelY_i*0.001f;
  doc["accelZ"]     = state.accelZ_i*0.001f;
  
  // IMU - Giroscopio ¡AGREGADO!
  doc["gyroX"]      = state.gyroX_i*0.01f;
  doc["gyroY"]      = state.gyroY_i*0.01f;
  doc["gyroZ"]      = state.gyroZ_i*0.01f;
  
  // PID
  doc["pidError"]   = state.pidError_i*0.01f;
  doc["pidOutput"]  = state.pidOutput_i*0.01f;
  doc["pidAngle"]   = state.pidAngle;
  doc["kp"]         = state.kp_i*0.01f;
  doc["ki"]         = state.ki_i*0.01f;
  doc["kd"]         = state.kd_i*0.01f;
  doc["currentRPM"] = state.currentRPM_i*0.1f;
  
  if (serialBuf.length()>0) {
    doc["serial"] = serialBuf;
  }
  
  String out; 
  out.reserve(768);  // Aumentado para datos adicionales
  serializeJson(doc,out);
  webSocket.broadcastTXT(out);
  serialBuf="";
}

// ======= SIRENA CONTROL =======
void startSiren() {
  siren.active    = true;
  siren.startTime = millis();
}
void stopSiren() {
  siren.active = false;
  noTone(cabezaPin);
}
void handleSiren() {
  if (!siren.active) return;
  uint32_t t = (millis() - siren.startTime) % siren.period;
  float phase = float(t) / siren.period;
  if (phase > 0.5f) phase = 1.0f - phase;
  uint16_t f = siren.freqLo + (siren.freqHi - siren.freqLo) * (phase * 2.0f);
  tone(cabezaPin, f);
}

// ======= BLINK CONTROL =======
void pickNewBlink() {
  curPatternIdx = random(N_PATTERNS);
  curBlinkStep  = 0;
  blinkOn       = true;
  nextBlinkTime = millis();
  blinkPatternFinished = false;
}

void handleBlinkPWM() {
  uint32_t now = millis();
  if (now < nextBlinkTime) return;
  
  blinkOn = !blinkOn;
  analogWrite(ojoIzqPin, blinkOn ? PWM_MAX : PWM_MIN);
  analogWrite(ojoDerPin, blinkOn ? PWM_MAX : PWM_MIN);
  
  uint32_t interval = blinkPatterns[curPatternIdx][curBlinkStep++];
  if (interval == 0) {
    // Patrón terminado - asegurar que los LEDs queden encendidos
    analogWrite(ojoIzqPin, PWM_MAX);
    analogWrite(ojoDerPin, PWM_MAX);
    blinkPatternFinished = true;
    delayFreePause(random(5000,12000));
    pickNewBlink();
  } else {
    nextBlinkTime = now + interval;
  }
}

// ======= WEBSOCKET CALLBACK =======
void onWsEvent(uint8_t num, WStype_t type, uint8_t* payload, size_t len) {
  if (type != WStype_TEXT) return;
  DynamicJsonDocument doc(256);
  if (deserializeJson(doc,payload,len)) return;
  const char* cmd = doc["cmd"];
  if (!cmd) return;

  if      (strcmp(cmd, "ping")       == 0) webSocket.sendTXT(num, "{\"cmd\":\"pong\"}");
  else if (strcmp(cmd, "playMelody") == 0) { appendSerialBuf("[MELODY]"); playMelodyAsync(); }
  else if (strcmp(cmd, "playAudio")  == 0) { appendSerialBuf("[AUDIO]");  playAudio(); }
  else if (strcmp(cmd, "startSiren") == 0) startSiren();
  else if (strcmp(cmd, "stopSiren")  == 0) stopSiren();
  else if (strcmp(cmd, "blinkNow")   == 0) pickNewBlink();
  else if (strcmp(cmd, "gamepad")    == 0) handleGamepadInput(doc);
  else if (strcmp(cmd, "unoOn")      == 0) { appendSerialBuf("[UNOON]"); setUnoOn(true); }
  else if (strcmp(cmd, "unoOff")     == 0) { appendSerialBuf("[UNOOFF]"); setUnoOn(false); }
  else if (strcmp(cmd, "dcOn")       == 0) { appendSerialBuf("[DCON]"); setDcOn(true); }
  else if (strcmp(cmd, "dcOff")      == 0) { appendSerialBuf("[DCOFF]"); setDcOn(false); }
  else if (strcmp(cmd, "setServos")  == 0) handleSetServos(doc);
  else if (strcmp(cmd, "setMRPM")    == 0) handleSetMRPM(doc);
  else if (strcmp(cmd, "setPID")     == 0) handleSetPID(doc);
}

// ======= GAMEPAD & COMMAND HANDLERS =======
void handleGamepadInput(JsonDocument& doc) {
  float fx = doc["lx"], fy = doc["ly"],
        frx= doc["rx"], fry= doc["ry"];
  float tl = doc["tl"], tr = doc["tr"];
  if (fabs(fx)<JOY_L_THRESHOLD) fx=0; if (fabs(fy)<JOY_L_THRESHOLD) fy=0;
  if (fabs(fx-joyState.lastFX)>JOY_L_THRESHOLD ||
      fabs(fy-joyState.lastFY)>JOY_L_THRESHOLD) {
    char buf[32];
    snprintf(buf,sizeof(buf), "[JOY_L:%.2f,%.2f]", fx, fy);
    Serial.println(buf); //Serial1.println(buf);
    appendSerialBuf(buf);
    joyState.lastFX=fx; joyState.lastFY=fy;
  }
  state.joyLX_i = fx*32767; state.joyLY_i = fy*32767;
  state.joyRX_i = frx*32767;state.joyRY_i = fry*32767;
  state.trig6_i = constrain((int)(tl*255),0,255);
  state.trig7_i = constrain((int)(tr*255),0,255);
  updateDCFromTrigger();
}

void handleSetServos(JsonDocument& doc) {
  uint8_t a1 = doc["a1"], a2 = doc["a2"];
  char buf[20];
  snprintf(buf,sizeof(buf), "[S,%u,%u]", a1, a2);
  Serial.println(buf); //Serial1.println(buf); 
  appendSerialBuf(buf);
  state.servo1 = a1; state.servo2 = a2;
}

void handleSetMRPM(JsonDocument& doc) {
  int rpm = doc["rpm"];
  char buf[20];
  snprintf(buf,sizeof(buf), "[MRPM,%d]", rpm);
  Serial.println(buf); //Serial1.println(buf); 
  appendSerialBuf(buf);
}

void handleSetPID(JsonDocument& doc) {
  float sp = doc["sp"], _kp=doc["kp"], _ki=doc["ki"], _kd=doc["kd"];
  state.setPoint_i=sp*100; state.kp_i=_kp*100; state.ki_i=_ki*100; state.kd_i=_kd*100;
  char buf[32];
  snprintf(buf,sizeof(buf), "[PIDT,%.2f,%.2f,%.2f,%.2f]", sp,_kp,_ki,_kd);
  Serial.println(buf); //Serial1.println(buf); 
  appendSerialBuf(buf);
}

// ======= SETUP & LOOP =======
void setup() {
  pinMode(ledESP, OUTPUT);
  pinMode(audioPin, OUTPUT);
  pinMode(ojoIzqPin, OUTPUT);
  pinMode(ojoDerPin, OUTPUT);
  pinMode(cabezaPin, OUTPUT);
  
  // Inicializar LEDs encendidos
  analogWrite(ojoIzqPin, PWM_MAX);
  analogWrite(ojoDerPin, PWM_MAX);
  analogWrite(cabezaPin, PWM_MIN);

  Serial.begin(115200);
  //Serial1.begin(115200);
  Serial.setRxBufferSize(256);
  //Serial1.setRxBufferSize(256);
  serialBuf.reserve(128);

  initAudio();
  memset(&state, 0, sizeof(state));
  state.servo1 = state.servo2 = 90;
  state.motorTime = 1000; 
  state.motorSel = 1;
  state.setPoint_i = 2500; 
  state.kp_i = 100; 
  state.ki_i = 2; 
  state.kd_i = 50;
  state.currentRPM_i = 0;
  
  // Inicializar valores de giroscopio
  state.gyroX_i = 0;
  state.gyroY_i = 0;
  state.gyroZ_i = 0;

  WiFi.mode(WIFI_STA);
  WiFi.begin(ssid, password);
  WiFi.setAutoReconnect(true);
  WiFi.persistent(false);
  
  uint8_t attempts = 0;
  while (WiFi.status() != WL_CONNECTED && attempts < 100) {
    delay(100); 
    attempts++;
  }

  server.on("/", [](){
    server.send_P(200, PSTR("text/html"), INDEX_HTML);
  });
  server.begin();
  analogWrite(ledESP, LOW);
  delay(250);
  analogWrite(ledESP, HIGH);
  delay(250);
  analogWrite(ledESP, LOW);
  delay(250);
  analogWrite(ledESP, HIGH);

  webSocket.begin();
  webSocket.onEvent(onWsEvent);

  randomSeed(analogRead(A0));
  curPatternIdx = random(N_PATTERNS);
  curBlinkStep  = 0;
  nextBlinkTime = millis();
  blinkPatternFinished = false;
  
  // Mensaje de depuración
  Serial.println("ESP8266 iniciado - Esperando datos del giroscopio...");
}

void loop() {
  server.handleClient();
  webSocket.loop();

  // Parpadeo de ojos - modificado para mantener LEDs encendidos al final
  if (!inPause()) {
    uint32_t now = millis();
    if (now >= nextBlinkTime) {
      blinkOn = !blinkOn;
      analogWrite(ojoIzqPin, blinkOn ? PWM_MAX : PWM_MIN);
      analogWrite(ojoDerPin, blinkOn ? PWM_MAX : PWM_MIN);
      
      uint32_t interval = blinkPatterns[curPatternIdx][curBlinkStep++];
      if (interval == 0) {
        // Patrón terminado - asegurar que los LEDs queden encendidos
        analogWrite(ojoIzqPin, PWM_MAX);
        analogWrite(ojoDerPin, PWM_MAX);
        blinkPatternFinished = true;
        delayFreePause(random(5000,12000));
        curPatternIdx = random(N_PATTERNS);
        curBlinkStep  = 0;
      } else {
        nextBlinkTime = now + interval;
      }
    }
  } else {
    // Durante la pausa, mantener los LEDs encendidos si el patrón terminó
    if (blinkPatternFinished) {
      analogWrite(ojoIzqPin, PWM_MAX);
      analogWrite(ojoDerPin, PWM_MAX);
    } else {
      handlePWMFade();
    }
  }

  // Parpadeo de cabeza tipo sirena
  handleHeadSirenBlink();
  handleMelody();
  handleAudio();

  static uint32_t lastBroadcast = 0;
  uint32_t now = millis();
  if (now - lastBroadcast >= 20) {
    broadcastState();
    lastBroadcast = now;
  }

  yield();
}

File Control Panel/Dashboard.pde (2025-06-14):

 import processing.serial.*;
import controlP5.*;
import java.util.regex.*;
import java.util.Arrays;

Serial port;
ControlP5 cp5;

ArrayList<String> irCodes = new ArrayList<>();
final int MAX_IR_CODES = 5;    // cuántos últimos verás en pantalla

// Datos IMU
float pitch, roll, yaw, temp;
int ax, ay, az, gx, gy, gz;
float ax_g, ay_g, az_g;

// Lectura ultrasonido
float distanceUS = 0;

// Historial
final int MAX_HISTORY = 200;
ArrayList<Integer> histAx = new ArrayList<>();
ArrayList<Integer> histAy = new ArrayList<>();
ArrayList<Integer> histAz = new ArrayList<>();
ArrayList<Float>   histAxG = new ArrayList<>();
ArrayList<Float>   histAyG = new ArrayList<>();
ArrayList<Float>   histAzG = new ArrayList<>();

// UI
boolean showX = true, showY = false, showZ = false;
boolean useRaw = true;

// Fuentes y colores
PFont fontH1, fontH2, fontText;
color pitchColor, rollColor, yawColor;

// Calibración inicial
boolean calibrating = true;
int calStart, calDur = 8000;

// Servos/Motores
int servo1Angle = 90, servo2Angle = 90;
int motorSelect = 0, motorVelocity = 0, motorTime = 1000;
int lastMotorSend = 0;

float sensorScale = 50;  // 50 px = 1 mm

void setup() {
  size(1280,720,P3D);
  surface.setLocation(100, 100);
  smooth(8);
  frameRate(144);

  pitchColor = color(255,128,0);
  rollColor  = color(128,0,255);
  yawColor   = color(0,255,255);

  fontH1   = createFont("Arial Bold",28);
  fontH2   = createFont("Arial",20);
  fontText = createFont("Arial",14);

  cp5 = new ControlP5(this);

  String[] ports = Serial.list();
  cp5.addDropdownList("serialPort")
     .setLabel("COM")
     .setPosition(300, 31)
     .setSize(160, ports.length*20)
     .setItemHeight(20)
     .setBarHeight(20)
     .setFont(fontText)
     .addItems(Arrays.asList(ports))
     .setValue(0);
  if(ports.length>0) openSerialPort(ports[0]);

  int togY = 400;
  cp5.addToggle("showX").setLabel("X")
     .setPosition(40, togY).setSize(30,15).setValue(true);
  cp5.addToggle("showY").setLabel("Y")
     .setPosition(80, togY).setSize(30,15);
  cp5.addToggle("showZ").setLabel("Z")
     .setPosition(120, togY).setSize(30,15);
  cp5.addToggle("useRaw").setLabel("Raw")
     .setPosition(160, togY).setSize(45,15).setValue(true);

  float telX = 40 + (width/2 - 80);
  cp5.addButton("calibrar")
     .setLabel("CALIBRAR")
     .setPosition(telX+10, 80)
     .setSize(80,30)
     .setFont(fontText);

  setupServosMotors();

  calStart = millis();
}

void draw() {
  background(18);

  if (calibrating) {
    drawCalibrationBarFull();
    return;
  }

  drawHeader();
  drawTelemetryPanel();
  drawDistancePanel();
  drawCubePanel();
  drawGraphSection();
  drawServosMotorsPanel();
}

void drawHeader() {
  textFont(fontH1);
  fill(220);
  textAlign(LEFT, CENTER);
  text("M0-V Dashboard", 40, 40);
}

void drawTelemetryPanel() {
  float x=40, y=80, w=width/2-80, h=240, p=16;
  noStroke(); fill(40,200);
  rect(x,y,w,h,8);

  textFont(fontH2); fill(200);
  text("Telemetría", x+p, y+p);

  textFont(fontText);
  float ty=y+p+32;
  fill(235); text("Pitch:", x+p,ty);    fill(pitchColor); text(nf(pitch,1,2)+"°", x+p+60, ty);
  fill(235); text("Roll:",  x+p,ty+24); fill(rollColor);  text(nf(roll,1,2)+"°", x+p+60, ty+24);
  fill(235); text("Yaw:",   x+p,ty+48); fill(yawColor);   text(nf(yaw,1,2)+"°", x+p+60, ty+48);
  fill(235); text("Temp: "+nf(temp,1,2)+" °C", x+p, ty+72);

  fill(235); text("Acel (raw):", x+p, ty+100);
  fill(#FF0000); text("X:"+ax, x+p+100,ty+100);
  fill(#00FF00); text("Y:"+ay, x+p+160,ty+100);
  fill(#0000FF); text("Z:"+az, x+p+220,ty+100);

  fill(235); text("Acel (g):", x+p, ty+124);
  fill(#FF0000); text("X:"+nf(ax_g,1,3)+"g", x+p+100,ty+124);
  fill(#00FF00); text("Y:"+nf(ay_g,1,3)+"g", x+p+160,ty+124);
  fill(#0000FF); text("Z:"+nf(az_g,1,3)+"g", x+p+220,ty+124);

  fill(235);
  text("Gyro → X:"+gx+"  Y:"+gy+"  Z:"+gz, x+p, ty+156);
}

void drawDistancePanel() {
  float x=40, y=80+240+5, w=width/2-80, h=30;
  noStroke(); fill(40,200);
  rect(x,y,w,h,8);
  textFont(fontH2); fill(200);
  textAlign(LEFT, CENTER);
  text("Ultrasonido: "+nf(distanceUS,1,2)+" cm", x+10, y+h/2);
}
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

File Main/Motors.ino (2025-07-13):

// dual_stepper_control.ino
#include <Servo.h>
#include <AccelStepper.h>

// Externs de Param.ino
extern const int enA, enB, in1, in2, in3, in4;
extern Servo servo1, servo2;
extern const int servo1pin, servo2pin;
extern const int motordc;
extern float MAX_RPM;

// Pines driver de paso a paso motor 1
const int dirPin1    = 2;
const int stepPin1   = 3;

// Pines driver de paso a paso motor 2
const int dirPin2    = 4;
const int stepPin2   = 5;

// Enable compartido (A0)
const int enablePin1  = A0;
const int enablePin2 = A1;
// Parámetros del stepper
const float STEPS_PER_REV = 2048.0;

// Objetos AccelStepper para motores 1 y 2 (DRIVER)
AccelStepper stepper1(AccelStepper::DRIVER, stepPin1, dirPin1);
AccelStepper stepper2(AccelStepper::DRIVER, stepPin2, dirPin2);

bool steppersEnabled = false;
float currentRPM1    = 0.0;
float currentRPM2    = 0.0;

// ----------------------- Inicialización -----------------------
void initSteppers() {
  pinMode(enablePin1, OUTPUT);
  pinMode(enablePin2, OUTPUT);
  disableStepper(1);
  disableStepper(2);
  
  // Configuración de velocidades y aceleraciones
  float maxStepsPerSec = (MAX_RPM / 60.0f) * STEPS_PER_REV;
  stepper1.setMaxSpeed( maxStepsPerSec );
  stepper1.setAcceleration( 10 * maxStepsPerSec );
  stepper1.setSpeed(0);

  stepper2.setMaxSpeed( maxStepsPerSec );
  stepper2.setAcceleration( 10 * maxStepsPerSec );
  stepper2.setSpeed(0);
}

void enableStepper(int m) {
  if (m == 1) digitalWrite(enablePin1, LOW);
  else        digitalWrite(enablePin2, LOW);
}

void disableStepper(int m) {
  if (m == 1) {
    digitalWrite(enablePin1, HIGH);
    stepper1.setSpeed(0);
    currentRPM1 = 0;
  } else {
    digitalWrite(enablePin2, HIGH);
    stepper2.setSpeed(0);
    currentRPM2 = 0;
  }
}

void setStepperRPM(int m, float rpm) {
  rpm = constrain(rpm, -MAX_RPM, MAX_RPM);
  if (fabs(rpm) < 0.01f) {
    disableStepper(m);
    return;
  }
  enableStepper(m);
  float stepsPerSec = (rpm / 60.0f) * STEPS_PER_REV;
  if (m == 1) {
    currentRPM1 = rpm;
    stepper1.setSpeed(stepsPerSec);
  } else {
    currentRPM2 = rpm;
    stepper2.setSpeed(stepsPerSec);
  }
}
// Llamar desde loop(): mueve ambos steppers y reporta RPM
void runSteppers() {
  static float lastSent1 = -1.0f;
  static float lastSent2 = -1.0f;

  stepper1.runSpeed();
  stepper2.runSpeed();

  if (fabs(currentRPM1 - lastSent1) > 1.0f) {
    Serial.print("[RPM1,"); Serial.print(currentRPM1,1); Serial.println("]");
    lastSent1 = currentRPM1;
  }
  if (fabs(currentRPM2 - lastSent2) > 1.0f) {
    Serial.print("[RPM2,"); Serial.print(currentRPM2,1); Serial.println("]");
    lastSent2 = currentRPM2;
  }
}

// ------------------- Control DC y servos (sin cambios) -------------------
bool motorDCRunning = false;
int  lastDCLevel    = -1;

void initMotors() {
  pinMode(enA, OUTPUT);
  pinMode(enB, OUTPUT);
  pinMode(in1, OUTPUT);
  pinMode(in2, OUTPUT);
  pinMode(in3, OUTPUT);
  pinMode(in4, OUTPUT);
  servo1.attach(servo1pin);
  servo2.attach(servo2pin);
  setServoAngles(90, 90);
  detenerDC();
  dcmotor(0);
}

void avanzar(int velocidad, int tiempo, int motor) {
  detenerDC();
  velocidad = constrain(velocidad, -255, 255);

  if (motor == 1 || motor == 3) {
    digitalWrite(in1, velocidad >= 0);
    digitalWrite(in2, velocidad <  0);
    analogWrite(enA, abs(velocidad));
  }
  if (motor == 2 || motor == 3) {
    digitalWrite(in3, velocidad >= 0);
    digitalWrite(in4, velocidad <  0);
    analogWrite(enB, abs(velocidad));
  }

  delay(tiempo);
  detenerDC();
}

void detenerDC() {
  analogWrite(enA, 0);
  analogWrite(enB, 0);
  digitalWrite(in1, LOW);
  digitalWrite(in2, LOW);
  digitalWrite(in3, LOW);
  digitalWrite(in4, LOW);
}

void setServoAngles(int a1, int a2) {
  a1 = constrain(a1, 0, 180);
  a2 = constrain(a2, 0, 180);
  servo1.write(a1);
  servo2.write(a2);
  Serial.print("Servos -> ");
  Serial.print(a1);
  Serial.print("°, ");
  Serial.print(a2);
  Serial.println("°");
}

void dcmotor(float level) {
  level = constrain(level, 0.0f, 1.0f);
  int pwm = round(level * 255.0f);
  if (pwm == lastDCLevel) return;
  analogWrite(motordc, pwm);
  lastDCLevel    = pwm;
  motorDCRunning = (pwm > 0);
}

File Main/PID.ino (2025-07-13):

// PID.ino — Control PID para dos steppers usando el ángulo 'pitch' del MPU6050

#include <Wire.h>             // Necesario para leer 'pitch' si está en el mismo proyecto
#include <AccelStepper.h>     // Para declarar extern setStepperRPM()

// Externs de Param.ino y tu módulo MPU/Steppers
extern float pitch;           // Ángulo medido por el MPU (°)
extern float setPoint;        // Punto de consigna (°)
extern float Kp, Ki, Kd;      // Ganancias PID
extern float MAX_RPM;         // Límite máximo de RPM para los steppers

// Prototipo de la función de control de steppers
void setStepperRPM(int motor, float rpm);

// Estado interno del PID
static float integral      = 0.0f;
static float previousError = 0.0f;

// -------------------------------------------------------------------------
// Inicializa el PID (se llama en setup())
void initPID() {
  integral      = 0.0f;
  previousError = 0.0f;
}

// Resetea el estado interno del PID (útil cuando cambies setPoint)
void resetPIDState() {
  integral      = 0.0f;
  previousError = 0.0f;
}

// -------------------------------------------------------------------------
// Calcula la diferencia angular mínima entre target y current, normalizada
// al rango [-180°, +180°].
static float angleError(float target, float current) {
  float err = target - current;
  if (err >  180.0f) err -= 360.0f;
  if (err < -180.0f) err += 360.0f;
  return err;
}

// -------------------------------------------------------------------------
// Debe llamarse periódicamente tras actualizar 'pitch'.
// Calcula el PID y ajusta la velocidad de ambos steppers.
void handlePID() {
  // Descartar lecturas inválidas o demasiado cercanas a cero
  if (fabs(pitch) < 0.1f) return;

  // 1) Error angular “wrappeado”
  float error = angleError(setPoint, pitch);

  // 2) Término integral (con tope para evitar wind‑up)
  integral += error;
  integral = constrain(integral, -1000.0f, 1000.0f);

  // 3) Término derivativo
  float derivative = error - previousError;

  // 4) Salida PID
  float output = Kp * error
               + Ki * integral
               + Kd * derivative;

  previousError = error;

  // 5) Convertir salida a RPM y limitar
  float rpm = constrain(output, -MAX_RPM, MAX_RPM);

  // 6) Aplicar a ambos steppers
  setStepperRPM(1, rpm);
  setStepperRPM(2, -rpm);

  // 7) Debug por serie (opcional)
  Serial.print("[PID,err=");
  Serial.print(error,  2);
  Serial.print(",int=");
  Serial.print(integral, 1);
  Serial.print(",der=");
  Serial.print(derivative, 2);
  Serial.print(",out=");
  Serial.print(output, 2);
  Serial.print(",rpm=");
  Serial.print(rpm, 1);
  Serial.println("]");
}

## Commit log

2025-06-14 version estable
    [experimento.f3z]
2025-06-14 control servo, leds, controles remotos
2025-06-30 Control lazo abierto casi terminado
    el proyecto está avanzando, tengo implementado el control de leds, motordc, servos, leds y parlante para sonidos y musica, me falta transmitir datos desde el arduino al esp8266, datos del gyroscopio 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
2025-07-04 graficos agregadps, pid, nema17 etc
